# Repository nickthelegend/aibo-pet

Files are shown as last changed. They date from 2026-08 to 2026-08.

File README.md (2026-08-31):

# HOTARU 2.0

An animated desk lamp that sees, hears and moves. Four MG996R joints on a
turntable base, a cone shade with a WS2812 ring for an eye, an I2S mic and
speaker, driven by an ESP32-S3.

The CAD is **pure Python** — no OpenSCAD, no CadQuery, no FreeCAD. Shapely
does 2D booleans, those profiles get extruded into watertight triangle
shells, and the shells are fused by the slicer. `cad/partlib.py` is the whole
kernel, about 600 lines.

**Every fastener is printed** except five M3 screws. No heat-set inserts, no
threaded rod, no bearings.

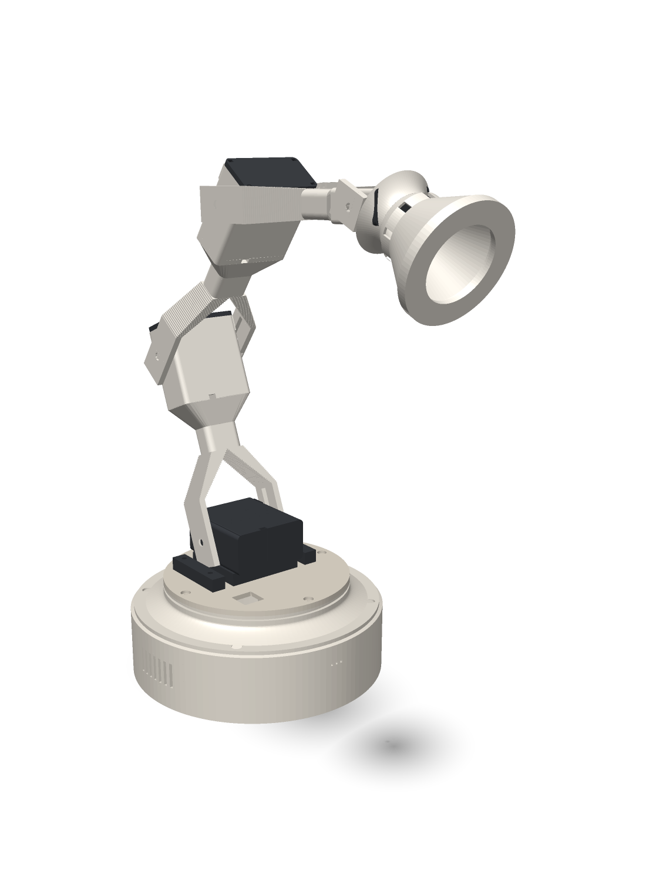
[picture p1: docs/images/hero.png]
HOTARU


> The hero image above is still a **v1** render. Rebuild the v2 shots with
> `cad/render_docs.py` before trusting it as a picture of what you'll get.

---

## Print it

Four plates on a Bambu **P1S** (256 × 256 bed, ~244 usable). No supports.

| Plate | Contains |
|---|---|
| `v2-plate-1-base` | the tub (the fixed outer shell) and the head |
| `v2-plate-2-arm` | link 1 and link 2, inner and outer, plus spacers and ledges |
| `v2-plate-3-turntable` | the disc, the tower that stands on it, the two locking keys, clamps, keycap |
| `v2-plate-4-cone` | the cone shade, its cap, and the printed bolt and screw trays |

STLs and a zip of all four: [`exports/v2/`](exports/v2/)

```bash
python3 -m venv .venv && .venv/bin/pip install -r requirements.txt
.venv/bin/python cad/v2_export.py     # build every part -> exports/v2/
```

19 printed objects across those four plates. Four of them are trays — 22
bolts, 6 clamps, 2 screws, 2 disc keys print as loose multiples on one sheet,
which is deliberate and is the one case where "this part is in pieces" is
correct.

---

## Bill of materials

### Electronics

| Part | What it does | Size the CAD assumes |
|---|---|---|
| **ESP32-S3 dev board** | the brain; USB-C charging reaches the outside wall through a charge well | 64 × 30 mm board, 1.6 mm PCB, 8.5 mm pin tails |
| **MAX98357A** | I2S class-D amplifier for the speaker | 20 × 18 mm breakout, 12 mm standoff to clear the screw terminal |
| **INMP441** | I2S microphone; hears through a 2.5 mm port in the wall | 15 mm round board, **press fit** (0.10 mm) |
| **Speaker, 40 × 20 mm** | voice out, through the grille slots in the low wall | 40 × 20 × 5.5 mm incl. magnet |
| **WS2812 ring, 12 LED** | the eye, mounted on the cone cap | 45 mm outer diameter, 4 pads |
| **Cherry MX switch** | the button, on top, with a printed keycap | 15.6 mm, wired out through the inward access slot |

### Motion

| Part | Joint | Travel verified |
|---|---|---|
| **MG996R** ×1 | pan (turns the whole turntable) | 180° |
| **MG996R** ×1 | shoulder | 180° |
| **MG996R** ×1 | elbow | 180° |
| **MG996R** ×1 | head tilt | 142.5° |

Each servo uses the **stock double horn from its own bag** — the moulded one,
not a printed replacement. The pocket is a single straight slot, not a cross,
because a cross pocket would let the real horn rattle a quarter turn round
into the empty arm.

### The only things you buy that aren't printed

| Part | Count | Where |
|---|---|---|
| **M3 × 10 screw** | 4 | tower flange down into the disc |
| **M3 screw from the servo bag** | 1 | horn onto the pan servo's output shaft, counterbored below the disc face |

Everything else — bolts, clamps, keys, screws — prints. The printed threads
are a coarse **M6 major, 2 mm pitch** profile, chosen because a 0.4 mm nozzle
cannot resolve a real M6's 1 mm pitch.

---

## Does it actually work?

There is no CSG in this kernel, which means a part is a union of overlapping
watertight shells rather than one solved solid. That is fast and it prints
fine, but it means a bug can be invisible: geometry that looks right in the
viewer and comes off the plate in two pieces.

So the design is checked by a stack of audits, and **each one exists because
the layer above it passed something that was broken**:

```bash
.venv/bin/python cad/v2_onepiece.py    # is each part ONE connected solid?
.venv/bin/python cad/v2_openings.py    # does every opening reach daylight?
.venv/bin/python cad/v2_insert.py      # can each part reach its seat?
.venv/bin/python cad/v2_sweep.py       # does the turntable complete its sweep?
.venv/bin/python cad/v2_motion.py      # does every joint swing?
.venv/bin/python cad/v2_wire_check.py  # does every cable have a real route?
.venv/bin/python cad/v2_bom_check.py   # is every component in there, and does it fit?
.venv/bin/python cad/v2_margins.py     # torque, thread shear, thermal
.venv/bin/python cad/v2_audit.py       # watertight, bed fit, interference, engagement
```

The rule they are written to: **a check is not evidence until it has been
proven to fail on broken geometry.** Several of them carry their own
self-test and exit non-zero if that self-test passes, because an all-clear
from a check that cannot fail is worth nothing.

Some of what they caught, in order of embarrassment:

- A crown that printed as a **loose arc**, floating 3.2 mm off the wall.
  Every audit passed it, because checks that compare parts to *each other*
  never notice a part detached from *itself*. That's why `v2_onepiece.py`
  exists.
- Grounding that crown then **bricked up every wall opening** — speaker,
  mic, MX wires, USB — from the outside. That's why `v2_openings.py` fires
  rays to daylight instead of trusting that a hole is a hole.
- A counterbore set to a ceiling **below the boss it was supposed to clear**,
  so it did nothing at all and the gap stayed at 0.15 mm.
- The mic port reading open on one run and bricked on the next, because
  probing exactly on a hole's axis lands on the mesh's polar seam where
  parity is a coin flip. The probes are jittered now.

---

## Numbers that are assumed, not measured

Stated plainly because they are the ones most likely to be wrong on your
bench, and no audit in this repo can catch them:

- **The stock MG996R horn** (`SHORN_L 54.0`, `SHORN_W 8.0`, `SHORN_T 2.5`,
  `SHORN_HUB_D 14.0`, `SHORN_SCREW_R 12.5 / 19.5`) comes from published
  dimensions, not from calipers on the part. If yours differ, change them in
  `cad/params.py` and re-export.
- Several component dimensions in `cad/params.py` carry a literal
  `# TODO verify` — the speaker, the amp breakout, the mic board diameter.
- **Layer adhesion on your printer and filament**, which is what the printed
  thread's 25 MPa assumption really rests on.

---

## Layout

```
cad/            the kernel, the parts, and the audit stack
  partlib.py      the whole CAD kernel — 2D profiles to watertight shells
  params.py       every dimension, in one place
  v2_parts.py     the v2 geometry
  v2_*.py         the audits
exports/v2/     v2 STLs, plates, and GLBs   <- print these
exports/        v1 STLs                     <- superseded, kept for reference
web/            the project site and parts browser
firmware/       ESP32-S3 sketches (bench tests; the motion core is not written)
videos/         the HyperFrames assembly video
docs/images/    renders (currently v1)
```

**v1 is superseded.** The v1 parts (`part_arms.py`, `part_base.py`,
`plates.py`, the STLs directly in `exports/`) describe an earlier machine
built around SG90s and an A1 mini bed. It is kept because the v2 web exporter
still shares code with it, not because you should print it.

---

## Status

CAD is print-ready and every audit above passes. **Firmware is not written** —
`firmware/` holds bench tests that sweep the servos, not the motion core.

## Licence

MIT — see [LICENSE](LICENSE). The grant covers the CAD sources and the
printable geometry, not just the Python, so you can print, modify and sell
these parts.

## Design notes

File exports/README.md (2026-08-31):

# exports/

**Print from [`v2/`](v2/).** That is HOTARU 2.0 — four plates, four MG996R
joints, printed fasteners.

The loose `.stl` files in this directory and the three `hotaru-*.glb` files
are **v1** and are superseded. They describe an earlier machine: SG90 head
servo, six plates, sized for an A1 mini bed, and a set of custom printed
screws that were replaced by M3s because the printed ones would not fit the
rotating base plate.

v1 is kept in the tree for two reasons — the v2 web exporter still shares
code with the v1 one (`cad/export_web.py`), and the project site's older
download links point here. It is not kept because you should print it.

| | |
|---|---|
| **print this** | `v2/v2-plate-1-base.stl` … `v2/v2-plate-4-cone.stl`, or `v2/hotaru2-plates.zip` |
| don't print this | everything else in this directory |

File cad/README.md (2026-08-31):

# HOTARU — CAD

Pure-python parametric CAD. No OpenSCAD, no CadQuery, no OCC.

    python3 -m venv .venv && .venv/bin/pip install -r requirements.txt
    .venv/bin/python cad/partlib.py        # kernel smoke test

## How it works

`partlib.py` is the kernel: 2D [shapely](https://shapely.readthedocs.io)
profiles get extruded (`prism`), lofted (`loft_solid`) or swept
(`revolve`) into closed triangle shells, which are written straight out as
binary STL / GLB.

Two rules keep it honest:

1. **No 3D CSG.** One printable part = a union of individually-watertight
   shells. Overlapping shells are fused by the slicer, not by us. 2D
   booleans (shapely) are encouraged — that is where all the real work
   happens.
2. **Overlap by `OVL` (0.2mm) where shells stack.** For an opening whose
   edges must land on exact spec numbers, use the *band-split trick*: the
   band carrying the opening stretches `OVL` into its solid neighbours,
   while each neighbour stops exactly at the opening edge — so the
   neighbour's cap face *is* the opening's edge.

`validate()` splits any mesh into connected shells and asserts each is
closed, edge-manifold, consistently wound and positive-volume. Every part
script exits non-zero if it isn't.

## Files

| File | Role |
|---|---|
| `partlib.py` | kernel: 2D profiles, `Mesh`, `prism`/`loft_solid`/`revolve`, `validate`, STL+GLB writers |
| `part_*.py` | one printable part each; runnable standalone, writes a preview GLB |
| `assembly.py` | builds every part in world position, writes print STLs + previews + `MANIFEST.json` |
| `audit_*.py` | read-only dimensional probes: component fit, print rules, SPEC compliance |

`SPEC.md` (repo root) is the dimensional contract. Numbers live there and in
the params block at the top of each part — never buried in the geometry.

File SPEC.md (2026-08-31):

# HOTARU — dimensional spec

Animated Pixar-style desk lamp: round base, three MG996R lift joints, SG90
head tilt, cone shade with a WS2812 ring, I2S mic + speaker, ESP32-S3.

All dimensions **mm**. Axes: X right, Y back (away from you), Z up.
Origin: centre of the base footprint, Z=0 at the base's outer bottom face.

Every number lives in [`cad/params.py`](cad/params.py); nothing downstream
hardcodes one. Measure your parts, edit that file, re-run `assembly.py`.
`TODO` in params = from a datasheet or listing, not from calipers.

## Kinematics

| Joint | Servo | Axis | Drives |
|---|---|---|---|
| base | MG996R | X, Z=82.65, Y=18.0 | lower arm pitch (no yaw) |
| shoulder | MG996R | 120.0 from base | upper arm |
| elbow | MG996R | 120.0 from shoulder | forearm |
| head | SG90 | 105.0 from elbow | shade tilt |

Reach 345 mm; 316 mm tall in the neutral pose.

Every joint is **driven one side, bearing-supported the other**. The drive
plate captures the horn in a cross recess — slot walls carry the torque,
screws only retain it axially — and the idler plate rides a stub axle on the
far housing wall. Servos sit in **clamshell cup + screw-on cap**, clamped by
the body with their tabs trapped in slots. The tab *hole* pattern is never a
load path, which matters: the brief's "20 mm c-c" matches no MG996R drawing.

## Base

Round turned form: cylinder Ø160 to Z=42, then a
**quarter-sine shoulder** lofted in to Ø118 at Z=58. The shoulder is
tangent to the cylinder where it leaves it, so they read as one turned piece
rather than a box with a chamfer. It only ever narrows going up, so the whole
silhouette is decorative *and* support-free.

**The height is the point.** 56 mm of interior, 37 mm of it clear above the
board — wire volume, so cable management is not an afterthought this time.

| Feature | Where | Detail |
|---|---|---|
| ESP32-S3 | X 6..70, Y -29..1, underside Z=16.0 | flat, USB-C + components UP, pins DOWN into 13.6 mm |
| USB-C | right, Y ±15 of -14.0, Z 15.5..23.0 | window cut through a **tunnel boss** |
| speaker | left, face X=-69.0, Y=-6.0 Z=22.0 | 7 slots x 2.2; sealed back volume behind X=-56.0 |
| mic | front, X=0.0 Z=30.0 | 3 x 1.6 ports + a wall counterbore the board drops into |
| amp | floor (0.0, 30.0) | four L-ridges |
| lid | — | **structural**: underside rib web (Z 50..58) carries the arm |
| lid rim | — | 4 M3s into the seat lugs + a snap bead on the skirt |
| bulk cap | floor (46.0, 46.0) | C-clamp, press fit |
| MX key | lid (-28.0, -30.0) | see below |
| seat lugs | (±53, 0), (0, ±53) | 4 short lid hold-downs, webbed into the rim |

The shoulder stops tapering at Z=52 and runs **straight to the top** — a lid
skirt dropping into a cone only fits at one height, and the first attempt
fouled the bore by 2.1 mm. The rebate is now a constant Ø113.2, with a snap
groove at Z=55 that the skirt's 0.45 bead clicks into.

**Component retention.** The speaker pocket is open at the top: the driver
drops in onto a shelf, framed on four sides, and `spk-clamp` screws down over
it into two posts that deliberately stop 0.4 mm *below* the pocket top, so
tightening preloads the driver instead of bottoming out. The mic sits in a
U-slot counterbore in the front wall — circular below centre, straight-sided
above, so the board drops in from the top and two full-height lips retain it
against the ports. Neither part relies on tape.

A round wall curves away from a flat board end, so the **USB tunnel boss** is
a flat land filling that gap with the window cut through it. Without it the
receptacle sits too deep for a plug to reach — the single thing a circular
base breaks that a square one does not.

### MX key socket

Plate section **exactly 1.5** (Z 59.9..61.4), cutout 14.1 x 14.1 — donor-keyboard
geometry, so a Cherry MX clips straight in. Below it the lid opens to
16.0 for 1.9 mm: the relief the latches spring into. Push it in
from above; it pops in and stays.

## Base joint

Bolts on top of the lid on an 8 mm plinth, its four M3s threading into
heat-set inserts in the **lid's own rib web**. There are no internal
bulkheads: load goes housing → rib → lid rim → seat ring → shoulder → wall →
floor, so nothing stands in the wiring bay.
Pivot height 82.65 is set by the **yoke's swing radius (18.87)**, not the
housing. The plinth has an open corridor at |X| 25.45..29.45 for the yoke to
sweep through, and the bolts sit outboard at ±35 to clear it — the boss OD has to miss the
corridor, not just its centre.

## Cone

Ø66 mouth tapering to Ø20 over 52 mm — 23.9° half-angle,
1.6 wall, 8 vent slots, apex left OPEN (no bridge, and it is the
ring's wire exit).

The tilt pivot sits at local Z=60, **behind** the cone — where the taper is
down to r=10.0, narrower than the servo housing's 18.65. That is the
only place a yoke can straddle a cone without burying itself in it. A
10 mm collar flares out at 37.6° to carry the yoke plates.

## Printed couplers

A true involute spline at the MG996R's 5.92 OD works out to ~0.37 mm per
tooth flank — under a 0.4 nozzle, so it will not print. The bore is instead a
root circle plus **25 round-bottomed scallops** of Ø0.9 that the metal teeth
seat into: bore reaches r=3.10 against tips at 2.96.

| Part | Use |
|---|---|
| `horn-mg996r` | printed cross horn, **stepped bore**: Ø6.5 head counterbore, Ø3.4 shank, then 4.5 mm of spline. A straight 5.45 bore would let the screw head drop into it and clamp nothing; 4.5 mm of engagement stays under the 4.7 mm of shaft that actually protrudes. |
| `horn-sg90` | printed cross horn for the head tilt |
| `horn-adapter` | captures the STOCK metal horn — zero printed-spline risk |
| `spline-test` | three bores at −0.1 / 0 / +0.1. **Print this first.** |

Torque ends up in the yoke's cross slot either way, so a loose spline costs
backlash, not a stripped joint.

## Print plates

Bambu A1 mini 180³, PLA, 0.2 mm layers, 3 walls, **no supports on any part**.

| Plate | Parts | Used | Why |
|---|---|---|---|
| `plate-1-test.stl` | horn-mg996r, spline-test | 118 x 48 x 6 | print FIRST -- verifies the printed spline before you commit |
| `plate-2-base.stl` | base | 160 x 160 x 58 | the round base; it owns the bed on its own |
| `plate-3-arms.stl` | arm-lower, arm-upper, arm-fore | 123 x 52 x 154 | the three segments, standing on their yokes |
| `plate-4-head.stl` | lid | 118 x 118 x 9 | cone (mouth down) + lid (top face down) |
| `plate-4-head-2.stl` | shade | 66 x 66 x 72 | cone (mouth down) + lid (top face down) |
| `plate-5-small.stl` | horn-adapter, base-joint, horn-sg90, cap-base, cap-shoulder, cap-elbow, cap-head | 167 x 100 x 52 | everything that is quick |

Arms print standing on the yoke: the two plates start as separate islands and
merge into the tube as the print rises. Yoke converge 42.7°, tube→housing
flare 38.8°, cone 23.9°, collar 37.6° — all inside the 45° rule.

## Electrical

- 4 servos on 4 hardware LEDC channels (no PCA9685 at this count)
- I2S0 → INMP441 (RX), I2S1 → MAX98357A (TX); separate controllers
- WS2812 ring on one GPIO via RMT
- **Split the 5 V rail at the USB-C connector**: one leg to the ESP32-S3, one
  to the servo bus, common ground, bulk cap across the servo rail *at the
  branch* — the clamp at (46.0, 46.0) is placed for that, not back at the input.
  Never feed servos from the board's onboard regulator.

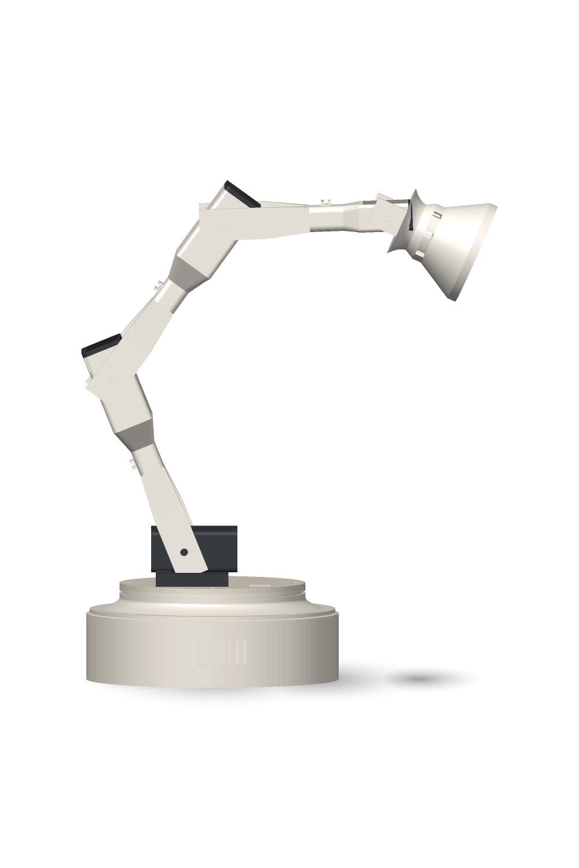
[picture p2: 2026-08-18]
docs/images/side.png

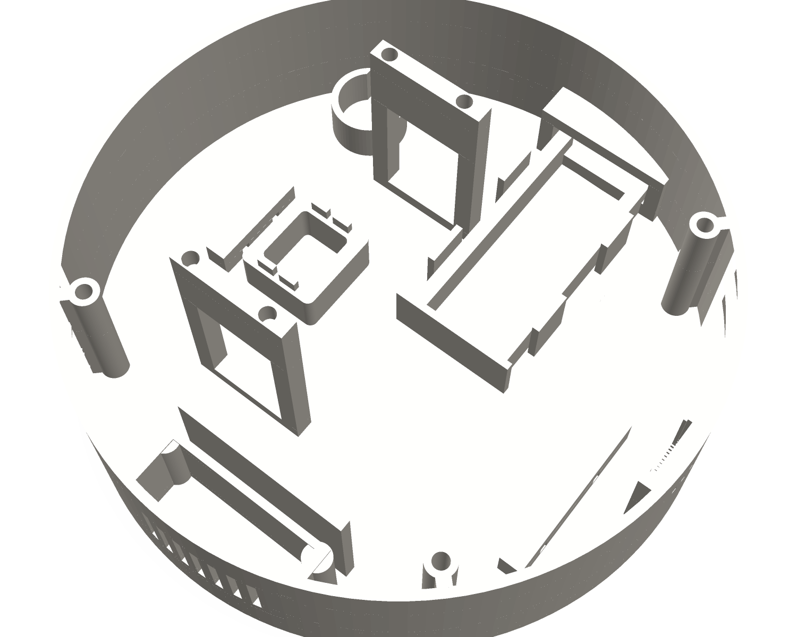
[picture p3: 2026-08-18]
docs/images/base-bay.png

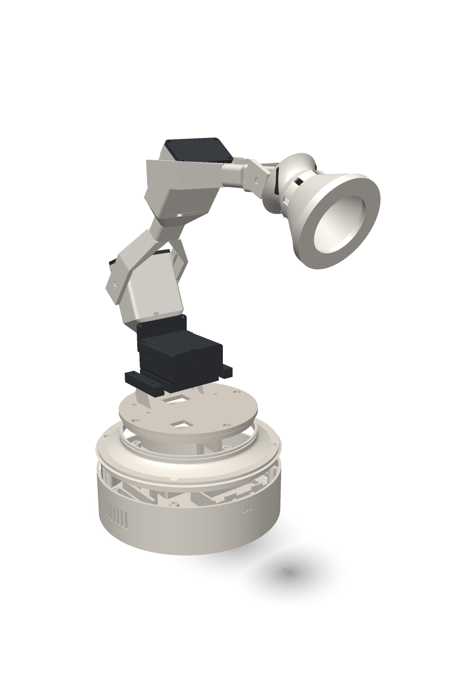
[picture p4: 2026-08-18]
docs/images/exploded.png

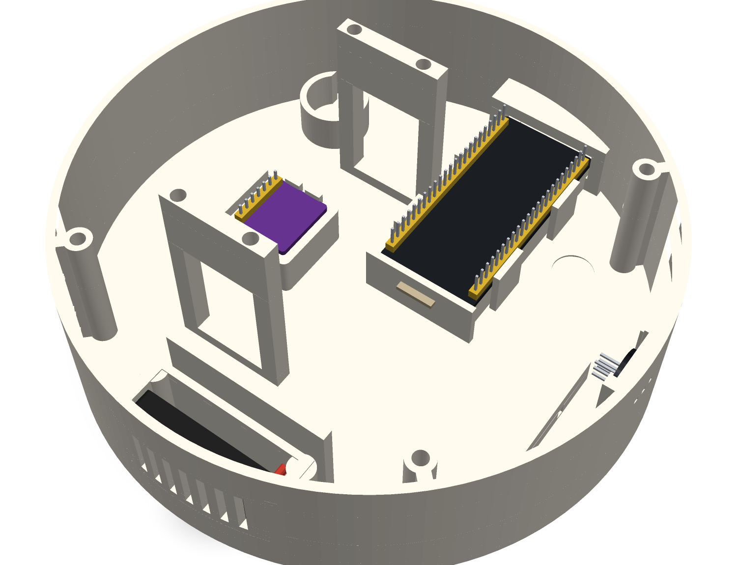
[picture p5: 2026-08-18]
docs/images/bay-populated.png

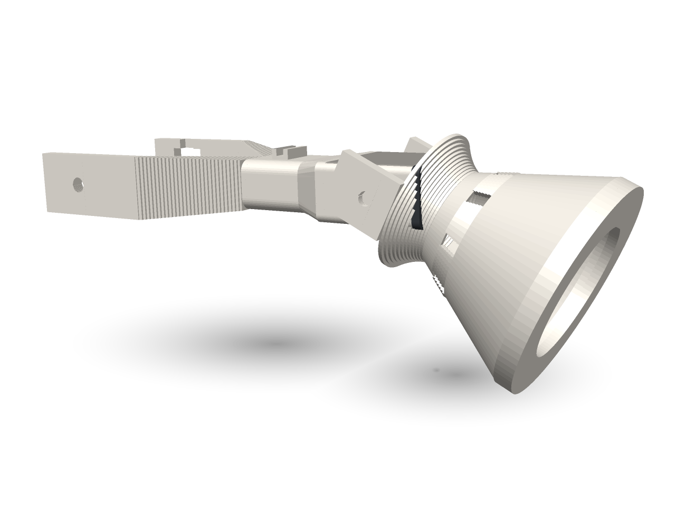
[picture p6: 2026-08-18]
docs/images/cone.png

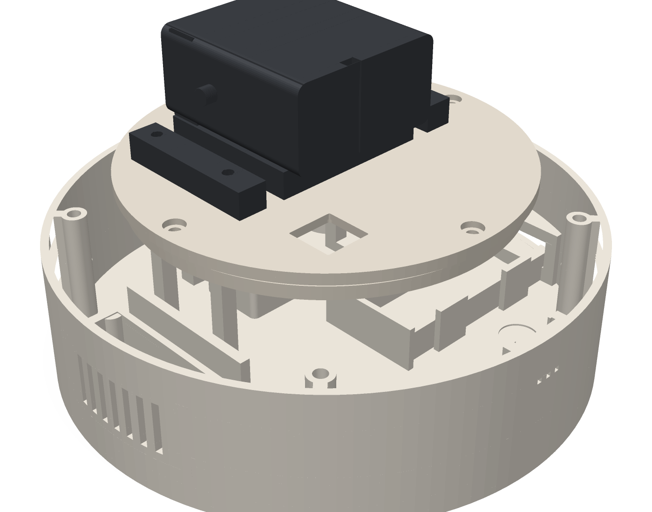
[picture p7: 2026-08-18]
docs/images/base-joint.png

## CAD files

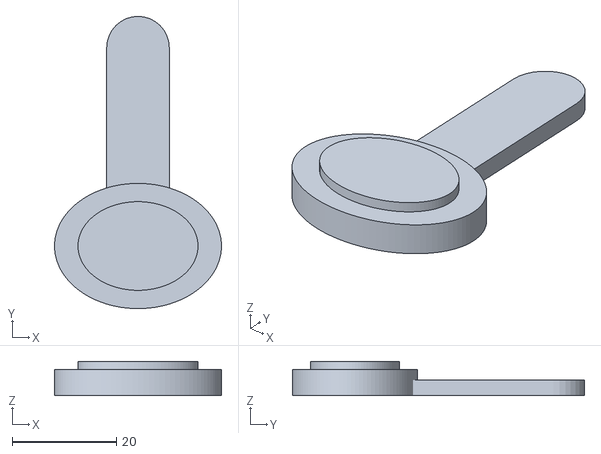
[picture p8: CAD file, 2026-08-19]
exports/band/band-pad.stl
32.0 x 56.0 x 6.60

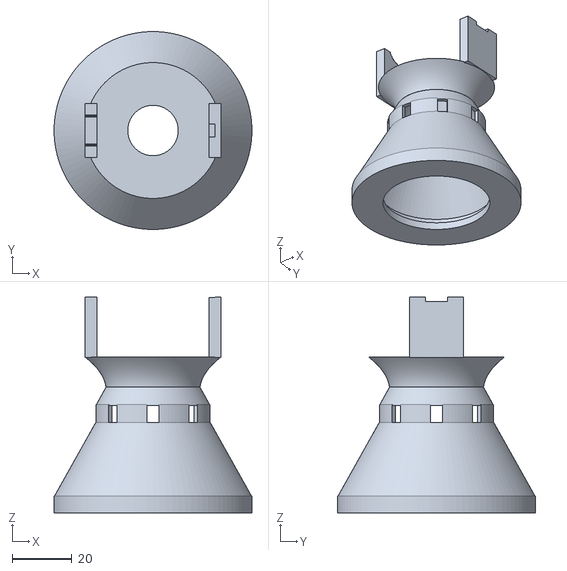
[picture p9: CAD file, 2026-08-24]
exports/plate-4-head-2.stl
66.0 x 66.0 x 72.0

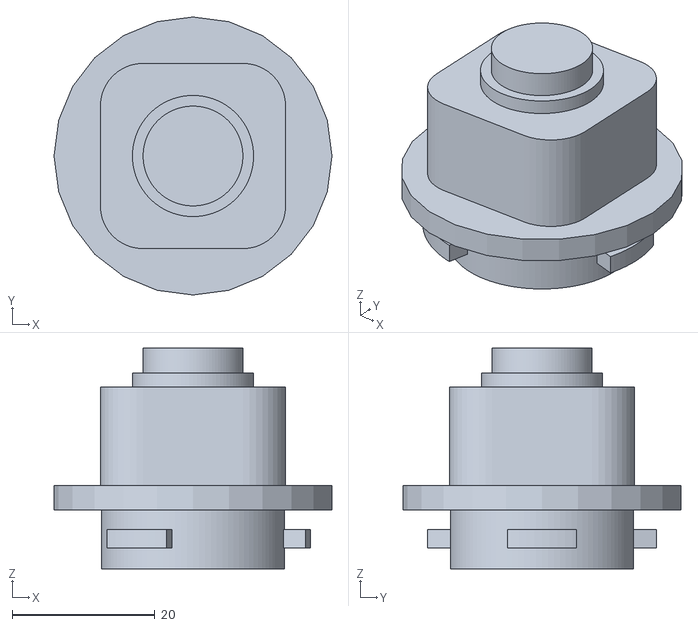
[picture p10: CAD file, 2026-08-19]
exports/band/band-cam.stl
39.0 x 39.0 x 31.0

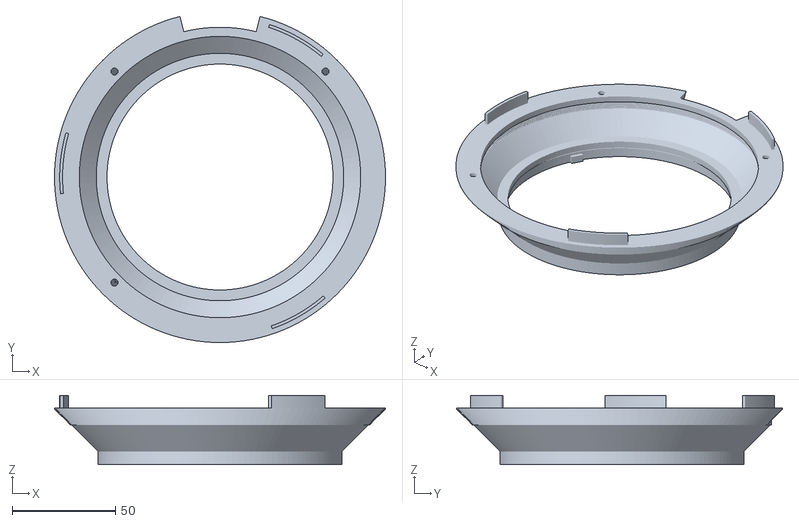
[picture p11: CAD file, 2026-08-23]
exports/plate-2b-shoulder.stl
160.0 x 157.6 x 33.4

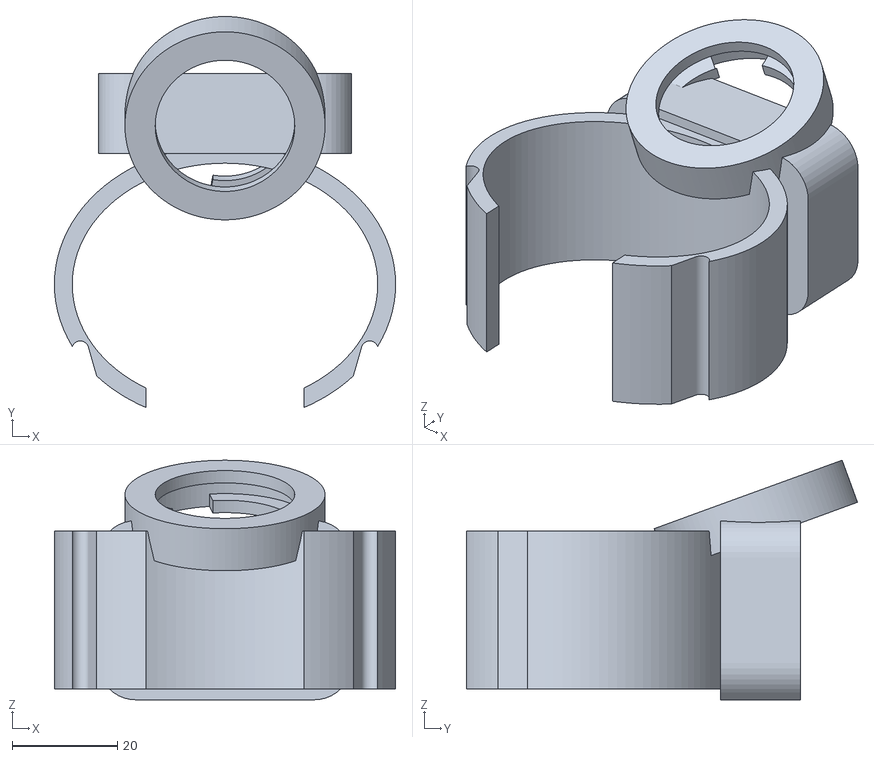
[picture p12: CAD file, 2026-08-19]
exports/band/band-cuff.stl
64.8 x 74.2 x 45.5

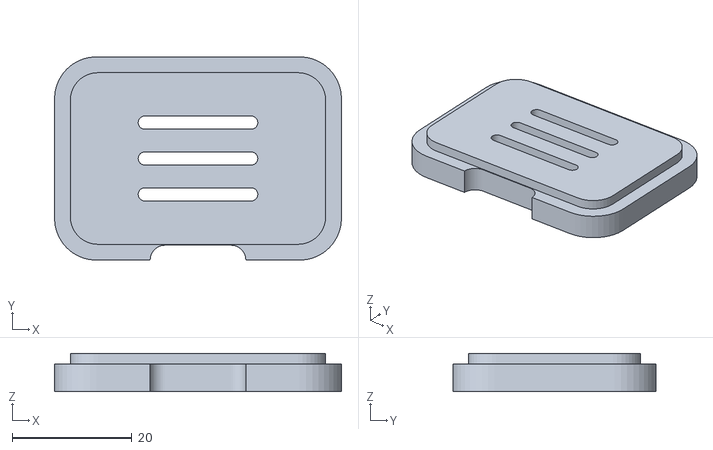
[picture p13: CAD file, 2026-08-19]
exports/band/band-cap.stl
48.0 x 34.0 x 6.40

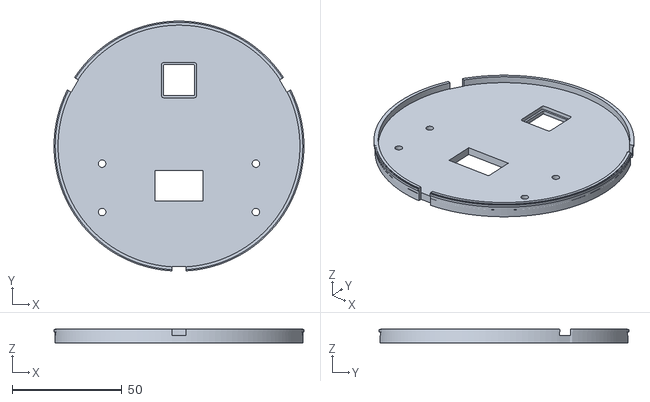
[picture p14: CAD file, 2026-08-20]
exports/lid.stl
113.8 x 113.7 x 6.40

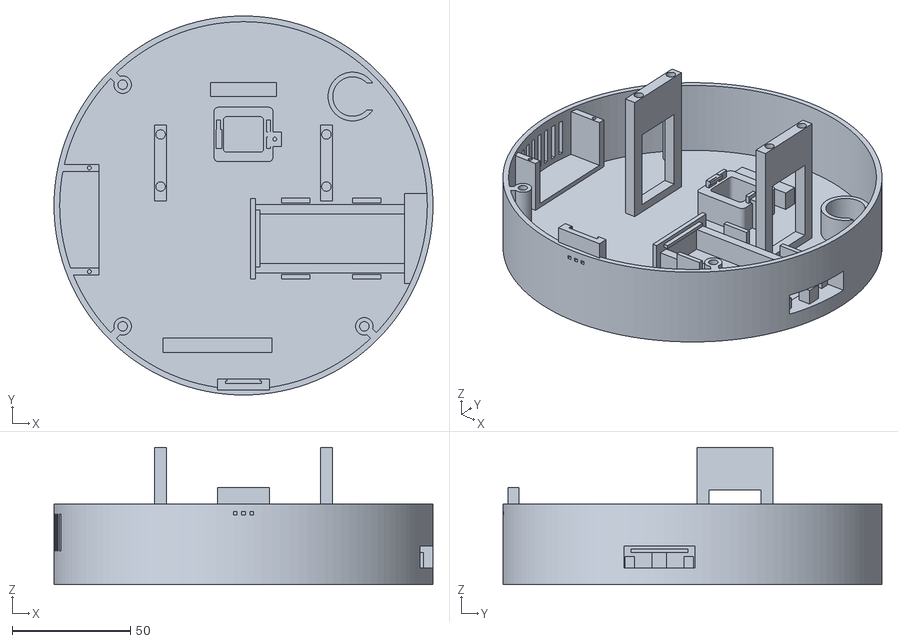
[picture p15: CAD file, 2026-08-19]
exports/plate-2-base.stl
160.0 x 160.0 x 58.0

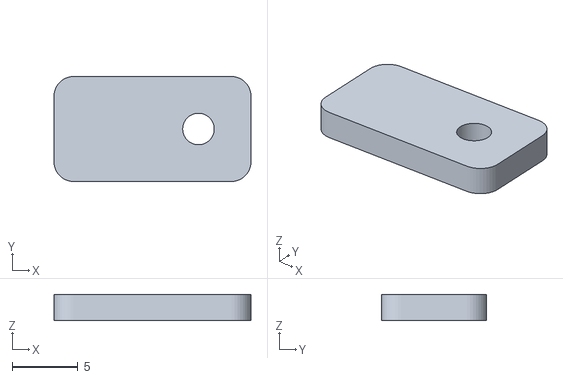
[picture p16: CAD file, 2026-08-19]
exports/amp-tab.stl
15.0 x 8.00 x 2.00

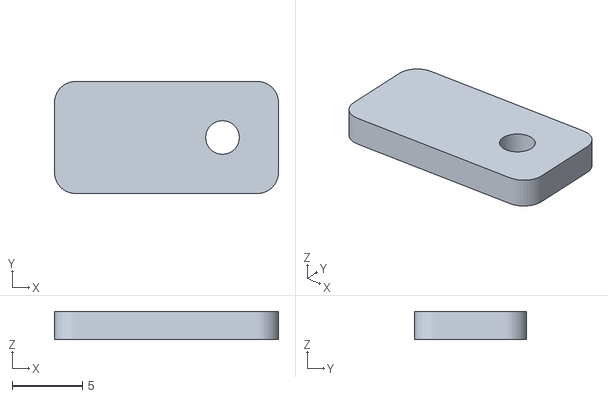
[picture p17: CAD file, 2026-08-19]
exports/esp-tab.stl
16.0 x 8.00 x 2.00

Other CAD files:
exports/v2/v2-conecap.stl
exports/v2/v2-clamps.stl
exports/shoulder.stl
exports/v2/v2-link2-out.stl
exports/plate-4-head.stl
exports/v2/v2-link2-in.stl
exports/v2/v2-plate-4-cone.stl
exports/v2/v2-link1-ledges.stl
exports/arm-fore.stl
exports/arm-lower.stl
exports/arm-upper.stl
exports/base-joint.stl
exports/base.stl
exports/cap-base.stl
exports/cap-elbow.stl
exports/cap-head.stl
exports/cap-shoulder.stl
exports/horn-adapter.stl
exports/horn-mg996r.stl
exports/horn-sg90.stl
exports/keycap.stl
exports/mic-tab.stl
exports/plate-1-test.stl
exports/plate-3a-arm-lower.stl
exports/plate-3b-arm-upper.stl
exports/plate-3c-arm-fore.stl
exports/plate-5-small.stl
exports/spk-clamp.stl
exports/spline-test.stl
exports/v2/shade.stl
exports/v2/v2-bolts.stl
exports/v2/v2-caphead.stl
exports/v2/v2-disc.stl
exports/v2/v2-disckeys.stl
exports/v2/v2-head.stl
exports/v2/v2-horns.stl
exports/v2/v2-keycap.stl
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

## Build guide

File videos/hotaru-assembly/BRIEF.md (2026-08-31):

---
workflow: general-video
flow: automation
storyboard: no
message: "The whole lamp goes together in one order, and every step of it has been checked."
destination: youtube
aspect: 1920x1080
language: en
length: 80s
audience: "someone who has the plates printed and the servos in a bag, about to build it"
---

## Intent

A build sequence for HOTARU 2.0, one part at a time, in the order the parts
actually go together. Not a marketing reel: the viewer has the prints on the
desk and wants to know what goes where, and in what order.

The order is not invented for the video. It is the order `cad/v2_insert.py`
verifies -- the closure audit walks every part to its seat along a straight
line and fails if one cannot get there. Using any other order in the video
would be showing an assembly the design has not been checked for.

## Notes

- Visuals come from the project's own CAD, not from stock or invented
  graphics: the parts are the real meshes.
- Four MG996R and the stock horns are the only bought hardware; the base
  fasteners are M3, everything else is printed.
- Inferred, not asked (the user's standing "just build it"): destination,
  aspect and language come from remembered defaults confirmed on
  xorv-launch and polaris-launch; length and audience are my call.

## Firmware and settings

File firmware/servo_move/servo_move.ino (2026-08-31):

/*
 * servo_move.ino — HOTARU motion core + bench test
 *
 * Board: ESP32-D0WD-V3 (WROOM-32 DevKit), esp32 core 3.x, ESP32Servo 3.2.1
 * Port:  /dev/cu.usbserial-0001   FQBN: esp32:esp32:esp32
 *
 * WHY THIS REPLACES THE STEP-AND-DELAY VERSION
 * Measured on the actual board: a 140 deg move took 5.57 s whether the step
 * delay was 2 ms or 27 ms. servo.write() blocks on the 50 Hz PWM frame, so
 * the "one degree per delay()" loop is pinned near 25 steps/s and its speed
 * knob does nothing. It also blocks, which is fatal once four servos, I2S
 * audio and a LED ring have to share the loop.
 *
 * Instead: hold a float position per joint and advance it toward its target
 * by (speed * dt) once per 20 ms frame -- one write per servo per frame, the
 * exact rate the servo consumes. Motion is smooth, speed is real deg/s, and
 * loop() never blocks.
 *
 * WIRING (per servo)
 *   brown  GND ---- ESP32 GND        <-- common ground, always
 *   red    V+  ---- 5V  (VIN/VBUS -- bypasses the 3V3 regulator)
 *   orange SIG ---- GPIO (below)
 * 1000-2200uF across 5V/GND at the board. One unloaded MG996R off a 3 A
 * charger is fine; four under load needs the split rail.
 *
 * Serial @ 115200:
 *   0..180    move active joint      j0..j3  select joint
 *   v<n>      speed, deg/s (default 120)
 *   s         sweep 30<->150         m  endpoints    c  centre
 *   a / d     attach / detach        t  timing self-test
 *   ?         help
 */
#include <ESP32Servo.h>
#include <esp_system.h>

// Classic ESP32: 6-11 are SPI flash, 34-39 are input-only, 0/2/12/15 are
// strapping pins (GPIO12 high at boot = 1.8 V flash = dead board).
// 13/14/27/26 avoid all of it.
static const int PINS[4] = {13, 14, 27, 26};
static const char* NAMES[4] = {"base", "shoulder", "elbow", "head"};
static const int N_ACTIVE = 1;          // bench: just GPIO13 for now

static const int  US_MIN = 500, US_MAX = 2500, SERVO_HZ = 50;
static const uint32_t FRAME_US = 1000000UL / SERVO_HZ;   // 20 000

struct Joint {
  Servo   servo;
  float   pos = 90, target = 90;
  float   speed = 120.0f;               // deg/s
  bool    attached = false;
} J[4];

int active = 0;
uint32_t lastFrame = 0;

void attachJoint(int i) {
  J[i].servo.setPeriodHertz(SERVO_HZ);
  J[i].servo.attach(PINS[i], US_MIN, US_MAX);
  J[i].servo.write((int)J[i].pos);
  J[i].attached = true;
}

// one 20 ms frame: advance every joint toward its target, write once
bool tick(float dt) {
  bool moving = false;
  for (int i = 0; i < N_ACTIVE; i++) {
    Joint &j = J[i];
    if (!j.attached) continue;
    float d = j.target - j.pos;
    float step = j.speed * dt;
    if (fabsf(d) <= step) j.pos = j.target;
    else                  j.pos += (d > 0 ? step : -step);
    j.servo.write((int)lroundf(j.pos));
    if (j.pos != j.target) moving = true;
  }
  return moving;
}

// block until the current move finishes (bench use only; the real firmware
// just lets tick() run inside the main loop)
uint32_t settle(uint32_t timeout_ms = 8000) {
  uint32_t t0 = millis();
  while (millis() - t0 < timeout_ms) {
    uint32_t now = micros();
    if (now - lastFrame >= FRAME_US) {
      float dt = (now - lastFrame) / 1e6f;
      lastFrame = now;
      if (!tick(dt)) return millis() - t0;
    }
  }
  return millis() - t0;
}

void moveTo(float a) {
  J[active].target = constrain(a, 0.0f, 180.0f);
  uint32_t ms = settle();
  Serial.printf("%s -> %.0f deg in %lu ms (%.1f deg/s cmd)\n",
                NAMES[active], J[active].target, (unsigned long)ms, J[active].speed);
}

void timingTest() {
  Serial.println(F("timing self-test (140 deg each way):"));
  for (float v : {60.0f, 120.0f, 240.0f, 400.0f}) {
    J[active].speed = v;
    J[active].target = 20; settle();
    uint32_t t0 = millis();
    J[active].target = 160; settle();
    uint32_t ms = millis() - t0;
    Serial.printf("   %6.0f deg/s -> %5lu ms  (%.1f ms/deg, actual %.0f deg/s)\n",
                  v, (unsigned long)ms, ms / 140.0f, 140000.0f / ms);
  }
  J[active].speed = 120;
  Serial.println(F("done"));
}

void help() {
  Serial.println(F("\n--- HOTARU motion core ---"));
  Serial.printf("  active joint: %s (GPIO%d)  speed %.0f deg/s\n",
                NAMES[active], PINS[active], J[active].speed);
  Serial.println(F("  0..180 move | v<n> speed | j<0-3> joint"));
  Serial.println(F("  s sweep | m endpoints | c centre | t timing | a/d attach\n"));
}

void setup() {
  Serial.begin(115200);
  delay(300);
  Serial.println(F("\nHOTARU motion core"));
  esp_reset_reason_t r = esp_reset_reason();
  Serial.printf("reset reason: %s\n",
                r == ESP_RST_BROWNOUT ? "*** BROWNOUT -- supply sagged ***"
                : r == ESP_RST_POWERON ? "power-on (normal)" : "other/normal");
  ESP32PWM::allocateTimer(0); ESP32PWM::allocateTimer(1);
  ESP32PWM::allocateTimer(2); ESP32PWM::allocateTimer(3);
  for (int i = 0; i < N_ACTIVE; i++) attachJoint(i);
  lastFrame = micros();
  help();
}

void loop() {
  uint32_t now = micros();
  if (now - lastFrame >= FRAME_US) {          // non-blocking: this is the
    float dt = (now - lastFrame) / 1e6f;      // only place servos are written
    lastFrame = now;
    tick(dt);
  }
  if (!Serial.available()) return;
  String cmd = Serial.readStringUntil('\n');
  cmd.trim();
  if (!cmd.length()) return;
  char c = cmd[0];

  if (isDigit(c))      moveTo(cmd.toFloat());
  else if (c == 'v') { J[active].speed = constrain(cmd.substring(1).toFloat(), 5, 600);
                       Serial.printf("speed = %.0f deg/s\n", J[active].speed); }
  else if (c == 'j') { active = constrain(cmd.substring(1).toInt(), 0, N_ACTIVE - 1);
                       Serial.printf("active = %s\n", NAMES[active]); }
  else if (c == 'c')   moveTo(90);
  else if (c == 'm') { moveTo(10); delay(300); moveTo(170); delay(300); moveTo(90); }
  else if (c == 't')   timingTest();
  else if (c == 's') { Serial.println(F("sweeping -- send anything to stop"));
                       while (!Serial.available()) { moveTo(30); moveTo(150); }
                       Serial.read(); Serial.println(F("stopped")); }
  else if (c == 'd') { for (int i=0;i<N_ACTIVE;i++){ J[i].servo.detach(); J[i].attached=false; }
                       Serial.println(F("detached")); }
  else if (c == 'a') { for (int i=0;i<N_ACTIVE;i++) attachJoint(i);
                       Serial.println(F("attached")); }
  else help();
}

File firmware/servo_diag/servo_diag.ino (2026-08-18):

/*
 * servo_diag.ino — find out WHERE the chain is broken.
 *
 * The servo is not moving. Three things must ALL be true; test them one at
 * a time instead of guessing:
 *   1. the GPIO actually drives        -> 'h' / 'l' / 'b'   (multimeter/LED)
 *   2. real servo pulses reach it      -> '1' '2' '3'       (horn must jump)
 *   3. the servo has 5V and shared gnd -> measure its own red/brown
 *
 * Pulses come straight from the LEDC hardware peripheral -- no servo
 * library, no timer ISR. 50 Hz, 16-bit: duty = us/20000 * 65535.
 *
 * Board: ESP32-D0WD-V3, GPIO13 (silkscreen "D13" on a DOIT DevKit V1).
 */
static const int PIN = 13;
static const int HZ  = 50;
static const int RES = 16;

bool pwm_on = false;

void setPulse(int us) {
  if (!pwm_on) { ledcAttach(PIN, HZ, RES); pwm_on = true; }
  uint32_t duty = (uint32_t)((us / 20000.0f) * ((1UL << RES) - 1));
  ledcWrite(PIN, duty);
  Serial.printf("  %d us @ %d Hz  (duty %lu / %lu)\n",
                us, HZ, (unsigned long)duty, (unsigned long)((1UL << RES) - 1));
}

void toDigital() {
  if (pwm_on) { ledcDetach(PIN); pwm_on = false; }
  pinMode(PIN, OUTPUT);
}

void help() {
  Serial.println(F("\n=== servo diagnostic — GPIO13 ==="));
  Serial.println(F("STEP 1  is the pin driving?   black probe on GND"));
  Serial.println(F("  h  hold HIGH  -> ~3.3 V     l  hold LOW -> ~0 V"));
  Serial.println(F("  b  blink 1 Hz x10"));
  Serial.println(F("STEP 2  do pulses reach it?   horn should JUMP each time"));
  Serial.println(F("  1  1000us (~0deg)   2  1500us (~90deg)   3  2000us (~180deg)"));
  Serial.println(F("  w  wiggle 1000<->2000 five times   0  pulses off"));
  Serial.println(F("STEP 3  power — probe the SERVO's own red/brown wires:"));
  Serial.println(F("  must read 4.8-5.2 V. If 0 V, red is not on 5V — that's it."));
  Serial.println(F("  3.3 V there = you're on the wrong rail; MG996R won't turn.\n"));
}

void setup() {
  Serial.begin(115200);
  delay(400);
  Serial.println(F("\nservo diagnostic ready (LEDC hardware PWM)"));
  toDigital();
  digitalWrite(PIN, LOW);
  help();
}

void loop() {
  if (!Serial.available()) return;
  String c = Serial.readStringUntil('\n'); c.trim();
  if (!c.length()) return;
  switch (c[0]) {
    case 'h': toDigital(); digitalWrite(PIN, HIGH);
              Serial.println(F("HIGH — expect ~3.3 V on GPIO13")); break;
    case 'l': toDigital(); digitalWrite(PIN, LOW);
              Serial.println(F("LOW — expect ~0 V")); break;
    case 'b': toDigital(); Serial.println(F("blinking..."));
              for (int i=0;i<10;i++){digitalWrite(PIN,HIGH);delay(500);
                                     digitalWrite(PIN,LOW);delay(500);}
              Serial.println(F("blink done")); break;
    case '1': setPulse(1000); break;
    case '2': setPulse(1500); break;
    case '3': setPulse(2000); break;
    case 'w': Serial.println(F("wiggling 5x — WATCH THE HORN"));
              for (int i=0;i<5;i++){ setPulse(1000); delay(700);
                                     setPulse(2000); delay(700); }
              setPulse(1500); Serial.println(F("wiggle done")); break;
    case '0': if (pwm_on) { ledcDetach(PIN); pwm_on = false; }
              toDigital(); digitalWrite(PIN, LOW);
              Serial.println(F("pulses off — servo limp")); break;
    default:  help();
  }
}

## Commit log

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2026-08-18 Cut the speaker pocket's back out; the driver would not go in
    The pocket had a back. `window` stopped at xf, so `land.difference(window)`
    left a 2 mm lip spanning the driver's full 40.8 x 20.8 mm face. Front was the
    grille wall, back was that lip, ends were the rails, bottom was the shelf --
    a closed box. The leads had nothing to come out of, and the only way to fit
    the driver at all was to drop it down a 20.8 mm slot from above.
    The window now runs clear through the land's back face. What is left of the
    frame is the two end rails and nothing else: the driver goes in from the back
    and the leads come out the same way.
    spk-clamp grows two tongues to replace what the lip was doing. With the b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
    [base.stl, plate-2-base.stl, plate-5-small.stl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]
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2026-08-18 Snap groove was cutting the wrong side of the shoulder wall
    Measuring the assembled silhouette to confirm the lid step was gone turned up
    a second one 3 mm below it:
    Z55.0 r59.00
    Z55.5 r57.05 step -1.95
    Z56.5 r57.05
    Z57.0 r59.00 step +1.95
    The snap groove is meant to recess the BORE so the lid's bead has somewhere
    to click into. It was
    ring2d(circle(BASE_TOP_D), circle(SEAT_IN + 2*SNAP_BEAD))
    which is the OUTER slice of the wall, r57.05..r59.00. Cutting that took a
    1.95 mm channel right round the outside of the base and left the inner
    0.45 mm standing -- under a single 0.4 mm perimeter, so the slicer would
    either drop it or lay one thin bead of plastic a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
    [plate-2b-shoulder.stl, shoulder.stl]
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2026-08-19 Shoulder taper printable: straight, and given room to be shallow
    Rim-down does not fix it, and I measured before doing it. The shoulder is a
    SHELL: when it necks in going up, the inner surface is the one hanging. Turn
    it over and the overhang just moves to the outer surface -- and gets worse:
    as modelled (skirt down) 5695.9 mm2 worst 73.1 deg
    flipped (rebate down) 6660.1 mm2 worst 73.1 deg
    The angle is identical either way because the angle is the TAPER, not the
    orientation. So the taper had to change.
    Two things did it:
    profile quarter-sine -> straight. A sine puts its steepest slope right at
    the rim, pi/2 times the average. Same height, same diameters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
    [base.stl, lid.stl, plate-2-base.stl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]
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2026-08-19 Audit every interface for "what actually holds this on"
    Three times now an interface has existed in the comments and not in the
    geometry -- speaker pocket, arm yokes, servo cup caps -- and each was found
    by accident, late, while looking at something else. The pattern never varied:
    prose asserts a fixing, nothing checks it.
    cad/audit_interfaces.py asks that one question of all 22 interfaces in the
    machine and will not take prose for an answer. Each row names the mechanism
    AND carries a predicate that reads geometry or params; a row whose mechanism
    is NONE fails the run.
    Two came back NONE:
    ESP32-S3 sat on two rails inside a cage that stood BESIDE it. Nothing
    over the board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
    [amp-tab.stl, base.stl, esp-tab.stl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]
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2026-08-19 Logo, parts viewer with raw STL links, motion pass, deploy server
    LOGO. Wordmark drawn as paths, not set in type -- the site's display face is
    a system stack and a logo cannot depend on which one a machine resolves. The
    O is the lamp's shade seen head on, with an arm and base hooking out of it so
    it reads as a lamp rather than a lollipop. Structural fills use currentColor;
    the blue shade and pink centre are fixed. mark.svg is the tab icon, drawn to
    survive 16 px: one silhouette, two fills, nothing that closes up.
    Two things caught while making it. `--` is illegal inside an XML comment and
    silently broke logo.svg entirely. And currentColor does not cross an <img> or
    <object> boundary, so the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
2026-08-19 Keep the loose-parts tray out of the hero; drop a ticker claim the audit contradicts
    The rig GLB carries the tray of unplaced parts so the viewer can show all 22.
    The hero is a portrait of the lamp, so it filters them out rather than having
    horns and retainers floating beside the base.
    Ticker still read "NO SUPPORTS". The parts section had already been corrected
    -- the shade yoke collar is 51 degrees and the overhang pass flags it -- so
    the ticker was the last place still making a claim the audit disagrees with.
2026-08-19 Version asset URLs by content hash so a redeploy actually lands
    Two fixes shipped and neither reached the browser: the hero kept showing the
    parts tray and the ticker kept claiming NO SUPPORTS, both served from a
    cached app.js while the server had the correct file. Dropping the max-age
    was not enough on its own -- a copy already cached under the old hour-long
    policy stays valid for that hour no matter what the server says next.
    export_web.py now stamps every asset URL with a hash of that asset own bytes,
    so the version changes when and only when the file does. gl.js is imported
    from JS rather than referenced in HTML, so its specifier gets stamped too.
    Combined with no-cache this is belt an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
2026-08-20 Print the shoulder rim-down; the lid lugs were cantilevered into thin air
    The first shoulder came off the bed with its four screw holes hanging in
    space, and every audit had passed it. Cause, measured rather than guessed:
    The lugs are a boss at r48 webbed outward to r56.8, extruded from Z48. At
    Z48 the taper's inner wall is at r63.6, so the web stops 6.8 mm short of it
    and the whole lug assembly is attached to nothing until the rebate ring
    appears at Z54.8. Six and a half millimetres of it just dangles.
    It cannot be gusseted from below either. The taper's bore is inner(z) =
    111.6 - z, exactly 45 degrees, so a 45 degree rib from the wall runs
    parallel to it and never gains ground on the bos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
    [plate-2b-shoulder.stl]
2026-08-20 Regenerate exports/shoulder.stl -- it was stale and still un-flipped
    The flip commit rebuilt the PLATE but not the individual part STL, because
    those are written by assembly.main() and the flip only went through
    plates.py and export_web.py. exports/shoulder.stl was last written on 19 Aug,
    before the fix, so the parts list on the site was still serving the
    orientation that printed with its screw holes in mid air. Anyone downloading
    a single part instead of the plate would have reprinted the same failure.
    Verified after regenerating: same triangle count and byte-identical Z
    profiles against plate-2b-shoulder.stl, so both are now the same part in the
    same orientation, differing only by the pla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
    [shoulder.stl]
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2026-08-20 Kill the lid screws: continuous seat ledge and three keys instead
    The printed joint had three separate faults and only one of them was the
    lugs. Reported from the bench: the lugs hang in air, the lid is loose in the
    bore, and the lid spins freely.
    Screws gone. The four M3 lugs reached 12 mm into a bore whose wall recedes at
    exactly 45 degrees, so nothing could ever support them from below, and they
    were also the only thing resisting rotation. Both jobs move to the ring:
    seat ledge a continuous 2.0 mm step, 1.85 mm of bearing all the way round
    instead of four points, built as a stack of rings that each
    run from the LOCAL bore inward to a constant radius
    t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
    [lid.stl, plate-2b-shoulder.stl, plate-4-head.stl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]
2026-08-20 The lid could not be inserted. audit_insert.py now checks that it can
    Spotted from the render, not by me: with the keys added there was no way to
    get the lid in. Measured and confirmed -- the keys neck the bore to O110.0
    while the lid's snap bead is O113.8 and its skirt O112.7, so everything below
    the plate fouled on the way down. Notching only the plate gave a lid that
    fits perfectly once seated and cannot be got there.
    Fix: the notches run the FULL height of the lid, through skirt and bead.
    The deeper problem is that no audit asked the question. Every check tested
    whether the ASSEMBLED parts fit; none tested whether a path exists to
    assemble them. audit_insert.py does, and it took three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
    [lid.stl, plate-4-head.stl]
2026-08-20 Make the tub and the shoulder actually fit. Three real clashes, measured
    The ring never seated on the printed tub and I had told the user there was no
    interference. That claim came from a parity point-in-solid test, which is
    invalid on these parts: they are unions of OVERLAPPING shells, so a point
    inside two shells crosses four surfaces, comes back even, and reads outside.
    cad/solidtest.py fixes it -- split into connected shells, parity per shell,
    OR the results. Self test included and it fails the naive way on two
    overlapping boxes, which is the whole point.
    With a test that works, three genuine clashes, all fixed in the SHOULDER
    because the tub is printed and is not changing:
    1. The tub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
    [plate-2b-shoulder.stl, shoulder.stl]
2026-08-23 Three locating pads: put back what deleting the skirt took away
    Deleting the skirt outright was wrong. It fouled the tub's internals so it
    had to go, but I replaced it with nothing and claimed the three M3s would
    locate the ring. They do not. They pass through 3.2 mm clearance holes, which
    stops the ring sliding once tightened and does not centre it at all. Bolted
    loosely or unbolted it floats about a millimetre in every direction, which is
    the crooked ring in the photo.
    The tub bore is actually free out to r77.75 across most of the circle. Only
    six narrow sectors have bulkheads or boss ribs reaching in past r75.9, and
    that is what the continuous ring caught on. So the fix is not less skirt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
    [plate-2b-shoulder.stl, shoulder.stl]
2026-08-23 Full sweep: pairwise part interference, and BUILD_REPORT.json
    Ran every audit over every plate and part, then did the check none of them
    did: PAIRWISE INTERFERENCE between all parts in the assembled pose, using
    solidtest so overlapping shells do not fool it. 12 placed parts, 14 pairs
    whose boxes overlap, 2200 jittered samples each.
    Three overlaps came back. One was mine and is fixed:
    shoulder <-> lid, 66 mm3 at z55.0..55.2. The seat ledge's top ring
    overshot the seat plane by OVL and held the lid 0.2 mm proud -- the same
    shell-fusion trick misapplied across a part boundary that I had already
    fixed once on the flange. Top ring now stops AT the seat; lower rings still
    overlap upwar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
    [plate-2b-shoulder.stl, shoulder.stl]
2026-08-24 Move the shade off the head cap: SHADE_TILT_Z 60 -> 74
    The pairwise sweep found the shade's collar and yoke arm running through the
    head cup's cap, 779 mm3 of solid overlap, plus 558 mm3 against arm-fore. I
    had left it flagged rather than fixed on the theory it might be the assembled
    pose. It was not: measured along the shade's own axis, the cap reaches r24
    exactly where the collar has material from r8.1. The parts genuinely
    interpenetrate.
    Cause: TILT put the cone's apex 8 mm from the head pivot, and the cap is
    35 mm across and reaches about 18 mm out from that pivot. There was never
    room.
    TILT is where the pivot bore sits in the shade's own frame, so raising it
    lengthens the yoke arm and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
    [plate-4-head-2.stl, shade.stl]
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2026-08-25 HOTARU 2.0: pan base, sandwich links, P1S plates. v1 deprecated
    Ground-up redesign against the reference mechanism the user supplied (a
    Chinese robot-arm 3MF, measured object by object) and the printed reality
    of v1. What 2.0 is:
    pan MG996R dead centre in the tub, spline up, driving the turntable
    disc 1:1 -- true 180 degrees in the plane. The reference gears a
    9 g servo into a Ø100 ring gear; through any such reduction a
    180-degree servo cannot reach 180 at the table, so the gearing
    is exactly what was NOT copied. What was: the slew bearing. The
    disc rides the tub RIM, so the arm's tipping moment lands on a
    Ø150 surf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
    [shade.stl, v2-clamps.stl, v2-disc.stl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]
2026-08-26 Restyle 2.0 to the reference: sculpted links, coin caps, pebble base
    "Mechanically right and visually stale" was the review, and it was correct.
    What the reference photos actually do, applied without moving one audited
    dimension:
    links tapered sculpted outlines with big rounded truss cutouts and three
    glow slots over the elbow servo. Styling cuts are clipped to the
    plate interior MINUS a functional keepout (bores, recess, window,
    standoff seats), so decoration can never eat a mechanism.
    caps the reference's slotted joint caps ARE screw heads, so ours are
    too: the shoulder yoke-screw grows a 26 coin-slot head, and a
    matching 32 trim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
    [v2-disc.stl, v2-link1-in.stl, v2-link1-ledges.stl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]
2026-08-26 2.0 verified end to end: servos in the model, contacts derived, rear crown
    The "broken" render was the world model missing everything that holds the
    sandwiches together. It now places the spacers, ledges, clamp screws, coin
    caps AND the four servos -- and auditing against the REAL servo meshes,
    not datasheet sketches, found and fixed:
    - the sandwich was sized to the servo's width; an MG996R crosses a joint
    along its HEIGHT (47.6 spline to tail). The whole joint stack is now
    derived once in v2_parts' header: case centred +/-21.45, drive faces
    with v1's 3.0 wall and 1.7 of spline into the horn socket, 1.5 of cross
    engagement both joints, elbow servo fully enclosed (no window, not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
    [v2-clamps.stl, v2-head.stl, v2-link1-in.stl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]
2026-08-26 v2 replaces v1 in the viewer, and the elbow gets its second plate
    Two things, both surfaced by looking at the thing rather than the audit:
    1. /viewer/ was still the ORIGINAL v1 model viewer. It was never part of
    the v2 work, so it quietly served the deprecated robot with no hint
    anything had moved. It is now the HOTARU 2.0 viewer: v2 GLBs, v2 part
    groups, plate views, and a plates-zip button. A copy is deployed at
    web/viewer/ pointing at the raw GitHub assets, since exports/ is outside
    the web root.
    2. The arm looked broken because THE ELBOW HAD A PLATE ON ONE SIDE ONLY.
    link2-out was truncated 32 mm clear of the axis to dodge the elbow
    servo's proud tail -- but the se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
    [v2-link1-in.stl, v2-link2-out.stl, v2-plate-2-disc.stl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]
2026-08-26 The disc did not turn. v2_sweep.py proves it does now
    You asked whether the disc actually rotates. It did not, and no existing
    audit could have told us: every one of them checks the robot STANDING
    STILL, which answers "do the parts fit", not "does the mechanism work".
    cad/v2_sweep.py rotates everything that turns with the disc -- disc, tower,
    both links, head, shade, screws and the three servos riding along -- through
    the full 180 in 7.5 degree steps and collision-tests each step against
    everything bolted to the tub. First run: BLOCKED at 22 of 25 steps.
    Cause: an MG996R's top face carries a secondary hump beside the output boss.
    It is fixed to the case while the disc turns over it, so the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
    [v2-disc.stl, v2-plate-1-base.stl, v2-plate-2-disc.stl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]
2026-08-26 MX key on top of the fixed base pod; MG996R head; O88 cone; drop-in yoke
    - turret: solid rear pod on the FIXED shell, MX drops into its top face
    (14.1 cut in a 1.5 plate, 16 relief, wire bore under the skirt line);
    printed blue keycap; crown parts around the pod; front-wall MX gone
    - two-part base per the reference: rotating disc + fixed shell/crown/pod,
    pan sweep still clears 180 with the pod in place
    - head joint is an MG996R -- one servo part number, four joints; nose is
    the drive-cheek stack (1.0 cbore, 1.7 spline, 1.5 cross), pockets derived
    from the servo mesh; lead pocket out the +Y wall
    - shade: O66 -> O88 mouth, deeper taper, spoked LED-ring carrier; yoke
    rebuilt as DROP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
    [shade.stl, v2-caphead.stl, v2-disc.stl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]
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2026-08-27 verify every listed component fits and is enclosed; fix what that found
    New audit v2_bom_check answers the three questions the geometry audits
    never did: is each component I actually bought PRESENT at its real size,
    how much air is around it, and is the electronics bay CLOSED. It found
    four real defects that every existing check had passed over, because they
    all compare printed parts to printed parts.
    - the amp's +Y locating pins landed under the solder-pad strip, and the
    ESP's -X pins landed under the WROOM can. Neither board has a hole
    where the standoff geometry wanted one. Pins are gone; both boards are
    now located by corner tabs that grip the PCB EDGE, which needs no hole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
    [v2-plate-1-base.stl, v2-tub.stl]
2026-08-27 close the three "not verified" holes: cables, margins, ventilation
    Wire routing was the real one. Two audits skipped servo leads as
    "flexible", so nothing proved a cable could get from the head servo to the
    ESP32 at all. v2_wire_check now VOXELISES the assembly at 3 mm, erodes the
    solid by one cell so surviving free space is genuinely cable-width, and
    breadth-first searches from each component's lead exit to its board.
    Deliberately not a waypoint list -- waypoints encode the answer you hoped
    for; a search can only find what is really there. All eight route: head
    servo 375 mm, LED ring 405 mm, the rest shorter.
    v2_margins replaces the other two disclaimers with arithmetic from this
    geometry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
    [v2-plate-1-base.stl, v2-tub.stl]
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2026-08-27 plates: put the whole arm on one plate
    Plate 2 held the disc and ONE link plate; the other three were stranded on
    plate 3. It sliced and printed fine, which is exactly the problem -- you
    cannot look at a plate carrying half of one arm and tell whether the file
    is broken or the design is. The link plates are two matched pairs and
    belong where you can count all four.
    plate 2 all four link plates, their spacer posts, ledges, yoke screws
    plate 3 the disc and the head block, with the two trim cups
    plate 1 tub, tower, clamp bars, keycap (unchanged)
    plate 4 cone, cap, horns, printed bolts, keys (unchanged)
    Renamed to match what they hold (plate-2-arm, plate-3-disc) and updated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
    [v2-plate-2-arm.stl, v2-plate-2-disc.stl, v2-plate-3-disc.stl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]
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2026-08-28 MX: access slot faces inward, outer face unbroken
    Cut outward it was the first thing you saw on the pod. Cut inward it opens
    above the rim, where the disc hides it once fitted, and you still reach the
    tags with the disc off -- which is when you are soldering anyway. The
    1.75 mm of wall behind the pocket stays, so from outside the pod is solid.
    Cross-section at x=0 confirms it: outer face solid at every height from 46
    to 54, pocket open inboard. The probe row that asserted the port was open
    BEHIND the tags is re-aimed inboard, and a new row asserts the outer face
    is still solid, so neither side can flip by accident.
    [v2-plate-1-base.stl, v2-tub.stl]
2026-08-28 fix four parts that printed in pieces; add the check that finds them
    The user printed the base and the rear crown came off the plate as a loose
    blue arc. It was never attached: the crown ring sat at r 78.2..81.2 and the
    turret pod at 77.5, against a tub wall that ends at 75 -- three millimetres
    of air, at every height, all the way round. Watertight, bed-fit,
    interference, closure, sweep, motion, BOM, cable and margin checks all
    passed it, because every one of them asks about the relationship BETWEEN
    parts and none asked whether a part is joined to itself.
    v2_onepiece answers that: it builds a graph of a part's shells with an edge
    wherever two interpenetrate, and counts connected components.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
    [shade.stl, v2-disckeys.stl, v2-head.stl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]
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2026-08-29 unbrick every wall opening; add the check that would have caught it
    Grounding the crown to the tub wall -- the fix that stopped it printing as
    a loose arc -- filled the annulus r72..81.2 all the way round below z=37.
    Every opening in that wall lives inside that annulus: the speaker grille,
    the USB charge well, the mic port and the MX lead window were all bricked
    up behind the new material. The wall had a hole; the crown behind the wall
    did not; from outside there was no hole at all. The user found three of
    them the only way left -- by trying to thread a wire and connect a board.
    The crown now carries whatever the wall opens: each band subtracts the
    WALL_OPEN geometry active over it, and cro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
    [v2-plate-1-base.stl, v2-tub.stl]
2026-08-29 fix the MX lead channel and the pan servo's running fit
    Ran every audit. Two real defects and one check that was lying.
    MX lead had NO route. The wall's band loop tested each opening against
    the band's STRETCHED top -- bands are grown by OVL so their shells fuse,
    and comparing the opening against that inflated ceiling drops any
    opening whose top lands on a band edge. The whole band then prints
    solid. Fixed to test the band's true top. The lead window also grew from
    8x8 to 12x12, which a 2 mm cable wanted anyway.
    Pan servo's boss ran 0.15 from the disc that TURNS over it: a O13.3 hub
    bore round a O13 boss. That is a rub, not a running fit. The bore is
    counterbored to O14 f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
    [v2-disc.stl, v2-plate-1-base.stl, v2-plate-3-disc.stl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]
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2026-08-31 rename the project to HOTARU, add the licence it was missing
    The repo was public with no LICENSE, which means nobody had permission to
    print, fork or sell it -- "public" and "open source" are not the same thing.
    MIT, and the grant names the CAD and the printable geometry explicitly so
    the hardware is covered and not just the Python.
    The name goes with it: aibo-pet -> hotaru, on GitHub and through every
    download URL in the site and the docs. Two things deliberately NOT renamed:
    * aibo.loompad.tech, which is live DNS and would 404 the parts page
    * everything under thenar/, which is a separate site
    The three v1 GLBs are renamed on disk too, so cad/assembly.py and
    render_docs.py still fin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
    [v2-disc.stl, v2-plate-1-base.stl, v2-plate-2-arm.stl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]
2026-08-31 README for v2, with the full BOM and what v1 was
    The README still described v1: A1 mini, SG90 head, six plates, 17 STLs.
    Anyone arriving at a public repo read a page for a machine that is not the
    one in exports/v2. Rewritten around what is actually built -- four plates on
    a P1S, four MG996R joints, every fastener printed but five M3s.
    Adds the bill of materials the repo never had: every board with the size the
    CAD actually assumes for it, every servo with its verified travel, and a
    separate short list of the only two things you buy that are not printed.
    Also states the numbers that are ASSUMED rather than measured -- the stock
    horn dimensions, the params still carrying `# TODO verify` -- b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
    [v2-plate-3-disc.stl]
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2026-08-31 publish the audited v2 geometry; fix a plate-2 overlap on the way
    The STLs in exports/v2 predated the stock-horn and M3 work, so anyone
    printing from the repo got the custom screw that would not fit the rotating
    base plate. Re-exported from the geometry all ten audits just passed:
    one-piece, banded-abut, openings-to-daylight, cable routing, joint motion,
    margins, BOM/fit, pan sweep, assembly closure, and the full v2_audit --
    78 PASS rows, no failures.
    The export refused to run at first, and it was right to. The four arm links
    are each 58 deep and were spaced 54 apart, so every neighbouring pair
    overlapped by 449 mm2. Note which check caught it: bed-fit passed the whole
    time, because the PLA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
    [shade.stl, v2-bolts.stl, v2-clamps.stl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]
